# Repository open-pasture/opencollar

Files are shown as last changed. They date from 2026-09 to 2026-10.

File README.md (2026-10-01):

# OpenCollar

Open hardware virtual-fence collar. Off-the-shelf parts, open protocol, works with any software that speaks it.

- `docs/BUILD-LOG.md` — dated record of every step, result, and decision
- `docs/PROTOTYPE-V0.md` — current state of the V0 prototype
- `docs/V1-DESIGN.md` — the V1 collar design and cost estimates
- `docs/MANUFACTURING.md` — how we get to 1,000 collars, and why FCC and carrier approval matter
- `docs/BOARD-DESIGN.md` — designing the custom board on a small budget
- `docs/DESIGN-PHASE.md` — board design toolchain and workflow (KiCad + SKiDL)
- `docs/COLLAR-FIRST-PRINCIPLES.md` — the slim collar worked out from first principles
- `docs/TEST-FIXTURE.md` — how every board gets tested, explained from zero, with pictures
- `docs/CARRIER-EXPLAINED.md` — every part on the carrier board, what it does, and where it sits in the collar
- `docs/STRATEGY.md` — product strategy and licensing
- `hardware/prototype-cart.md` — parts for the first prototype
- `hardware/orders-2026-09-26.md` — what was ordered and paid
- `hardware/tools.md` — tools for building a collar
- `hardware/bom.md` — parts list
- `hardware/photos/` — build photos

## Licence

OpenCollar is open so anyone can build, repair and improve their own collar.

| What | Licence | Folders |
| --- | --- | --- |
| Firmware, scripts and the protocol | [Apache-2.0](LICENSE) | `firmware/`, `protocol/`, and code anywhere else |
| Hardware and CAD (boards, enclosure, print files) | [CERN-OHL-W-2.0](LICENSES/CERN-OHL-W-2.0.txt) | `hardware/`, `mechanical/` |
| Docs, photos and renders | [CC BY 4.0](LICENSES/CC-BY-4.0.txt) | `docs/`, `hardware/photos/`, `mechanical/renders/` |

In plain terms:

- **Firmware and protocol:** use them for anything, including closed products. Keep the copyright notice and [NOTICE](NOTICE).
- **Hardware:** build, sell and change the boards and the enclosure. If you ship a modified version of these design files, publish your changes to them under the same licence. Your own add-ons can stay closed.
- **Docs:** reuse them with credit to openpasture.

Third-party files keep their own licences: `firmware/boards/makerdiary/` (Apache-2.0, plus Nordic's 5-clause licence where its headers say so) and `firmware/third_party/monocypher/` (CC0 or BSD-2-Clause).

The names openpasture and OpenCollar and the openpasture logo aren't covered by these licences; see [NOTICE](NOTICE). Contributing: [CONTRIBUTING.md](CONTRIBUTING.md).

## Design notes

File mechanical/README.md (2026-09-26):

# Mechanical

Printed parts for the collar. Every part is a Python script run by Blender, so a dimension change is a one-line edit and a rebuild. See `../docs/DESIGN-TOOLING.md` for why.

## Layout

| Path | What |
| --- | --- |
| `parts/*.py` | One script per part. Builds the geometry, then calls `oc.finish()` |
| `lib/oc.py` | Shared helpers: primitives, booleans, export, renders, checks |
| `lib/collar.py` | V1-alpha geometry (top unit, clamp bars, bay), shared by part scripts and the assembly |
| `assembly/collar.py` | The whole collar on a strap with the bought parts inside; saves `collar_v1_alpha.blend` and presentation renders to `renders/collar/` |
| `PRINT-LIST.md` | What to print, how, and the hardware list, for the fabrication partner |
| `lib/dims.py` | Every bought-part and tolerance dimension, with its source. Parts import from here |
| `exports/<part>/*.stl` | Print files for the fabrication partner (mm) |
| `reference/vendor/` | Vendor drawings and CAD (nRF9151 STEP, Eagle boards, vent and panel drawings). Local only, not committed; sources in `lib/dims.py` |
| `renders/<part>/` | Review images (front, side, top, bottom, iso, section) and `report.json` |

## Build

```sh
./build.sh            # every part
./build.sh seal_box   # one part
./package.sh          # rebuild everything, render the assembly, zip a share package into ../../output/
```

Needs Blender 5.x at `/Applications/Blender.app` (override with `BLENDER=/path/to/blender`). Takes a few seconds per part.

## What every build checks

A part fails the build (non-zero exit) unless:

1. **Manifold** (watertight) with outward normals.
2. **Walls** no thinner than the part's minimum (ray cast inward from every face, like Blender's 3D Print Toolbox).
3. **Size** matches the spec in the script.
4. **Clearance**: no overlap with reference bodies (the bought parts it has to hold).

It also reports volume, solid mass in the chosen material and downward-facing overhang area, and renders six views, including a section cut with cut faces in red.

## Parts

| Part | Files | Print |
| --- | --- | --- |
| `fit_test` | `fit_test.stl` | Flat, engraved face up |
| `seal_box` | `seal_box_box.stl`, `seal_box_lid.stl` | Box open side up; lid groove side up |
| `top_unit` | `top_unit_base.stl`, `top_unit_lid.stl`, `top_unit_clamp_bar.stl` (×2) | Base underside down, lid rim down, both with tree supports; bars flat |
| `bay` | `bay_cradle.stl`, `bay_ballast_module.stl` | Cradle on its side; module top face down |

The collar parts are draft 1: print the fit test and seal box first, put the winning sizes into `lib/dims.py`, rebuild, then print the collar.

## First print run (for the fabrication partner)

Material for everything: **ASA**, light grey or white, 0.2 mm layers, 6 perimeters (walls ≥ 2.4 mm), 40 % infill.

1. **`fit_test`**: one plate that sets our tolerances for your printer. Engraved numbers are the designed size in mm.
   - Row A: M3 × 4 brass heat-set inserts (Adafruit 4255). Press one into each hole with the iron; which holds best without bulging the plastic?
   - Row B: M3 screw clearance. Which lets an M3 screw drop through without rattling?
   - Row C: 2 mm silicone O-ring cord. Which grips the cord and leaves it standing about 0.5 mm proud?
   - Row D: M6 × 0.75 tap drill. Tap each and screw in the vent; which threads cleanly and seals on its O-ring?
2. **`seal_box`**: the seal the top unit will use. Fit 4 inserts, press about 213 mm of O-ring cord into the lid groove (superglue the butt joint), tap the lid's centre hole M6 × 0.75 for the vent, close it with 4 × M3 × 8 socket-head screws and a dry paper towel inside. Hold it 1 m under water for 30 minutes, then check the towel.

Send back: the winning size for each row, whether the box stayed dry, printer and material used, and any print problems (warping, stringing in holes, layer splits).

## Still to measure

Not published anywhere; needed before the top unit and strap mount are drawn. Calipers on the real parts:

- Strap thickness (Heritage 1-3/4" double-thick nylon)
- MAX-M10S breakout height (SMA is tallest), bq24074 board height
- GPS patch total height (ceramic + LNA board + shield) and cable length
- LTE flex antenna size and cable length
- Li-ion pack lead length

## Live sessions

For looking around and quick edits, Blender runs with the MCP for Blender add-on (auto-starts its server on port 9876 when Blender opens) and Claude Code has the `blender` MCP server registered. Anything worth keeping goes back into a script here.

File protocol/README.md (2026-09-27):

# Collar protocol, v1

How software talks to an OpenCollar: boundaries and configuration go down,
acks and position reports come up. Any software that speaks this can run the
collars; openpasture is the first. Its side of the same formats is
[`crates/op-protocol`](https://github.com/open-pasture/openpasture/tree/main/crates/op-protocol)
and the
[Device endpoints](https://github.com/open-pasture/openpasture/blob/main/docs/API.md#device-endpoints-collars)
section of `docs/API.md` in open-pasture/openpasture. The server contract they
grew from is in [`contracts.md`](contracts.md).

Status: firmware 0.2 implements everything here and checks it against the
shared test vectors. Boundary download over LTE waits for the SIM; until then
a signed command can be pasted on the serial console (see Provisioning).

## Principles

- **Fence logic runs on the collar.** The collar holds its boundary and cues
  the animal without the network. The server only changes what the boundary is.
- **The collar keeps the last good boundary.** A lost connection, a bad
  message, a power cut or a reboot never leaves an animal without a fence.
- **Versions only go up.** A collar accepts only versions above every version
  it holds.
- **Everything is signed and acknowledged.** A boundary counts as active only
  once the collar reports it applied.
- **GNSS time is the collar's only clock** for when a boundary takes effect.
  Nothing unsigned from a server sets it.
- **Only a crossing is cued.** See below.

## Collar rule: only cue a crossing

The collar cues "outside" only when the animal goes from inside (or the
warning zone) to outside under the boundary it holds.

- At boot and whenever a new boundary is applied, the fence is **unarmed**. The
  first fix inside the fenced area arms it. If that fix is in the warning
  zone, the warning cue plays at once, which is how a moved boundary pushes an
  animal.
- While unarmed and outside, the collar is silent and reports state `outside`.
  A boundary that leaves an animal outside never cues it.
- A crossing cues the outside tone for up to 10 s, then disarms. An animal
  walking back in is not cued in the warning zone on its way; a fix clear of
  the warning zone arms the fence again.
- Warning-zone cues are otherwise unchanged: louder toward the edge, at most
  20 s of continuous cueing, then 30 s of rest.
- Holes work the same way: walking into a hole is a crossing (outside tone up
  to 10 s, then disarm). A hole drawn on top of an animal leaves it outside
  after rearm: silent while it walks out, armed once clear.

Why: an audio cue only teaches when the animal can escape it by moving away
from the edge. A fence drawn on top of an animal, or behind it, gives no
direction, only noise. In the firmware this is `cue.c`.

## Limits

| Limit | LEGACY (fw 0.1, no `caps`) | V0 (nRF9151, fw 0.2) | V1 (+16 MB NOR) |
|---|---|---|---|
| Outer ring vertices | 3–64 | 3–128 | 3–128 |
| Holes | 0 | ≤ 16 | ≤ 16 |
| Vertices per hole | – | 3–32 | 3–32 |
| Total vertices | 64 | ≤ 384 | ≤ 384 |
| Slots (1 active + staged) | 2 | 16 | 32 |
| Slot bytes (all held records) | – | ≤ 24 576 | ≤ 262 144 |
| Command size | – | ≤ 12 288 bytes | ≤ 12 288 bytes |
| Ids (`command_id`, `herd_id`, `collar_id`) | ≤ 64 bytes | ≤ 64 bytes | ≤ 64 bytes |

A slot record takes 192 bytes plus 8 per vertex (`int32` lon and lat × 1e7,
lossless because the server rounds to 7 decimals): 3 264 bytes at most, under
400 for a typical strip. Vertex counts are taken after conversion to e7 with
consecutive duplicates and a closing vertex removed.

## Boundary command (down)

```json
{
  "command_id": "bnd_01J8...",
  "herd_id": "herd_01J7...",
  "collar_id": "col_01J9...",
  "version": 57,
  "effective_at": "2026-09-27T12:00:00Z",
  "boundary": [[-92.41,38.12],[-92.4,38.12],[-92.4,38.13],[-92.41,38.13]],
  "holes": [[[-92.406,38.124],[-92.404,38.124],[-92.404,38.126]]],
  "cue_mode": "track",
  "warn_m": 5.0,
  "hysteresis_m": 1.0,
  "sig": "base64..."
}
```

- Rings are unclosed `[longitude, latitude]` arrays, WGS 84, at most 7
  decimals. Winding is ignored. `holes` is omitted when empty.
- `herd_id`: the herd the boundary is for. A collar rejects another herd's
  boundary (`wrong_herd`). Commands without it (older servers) are accepted.
- `collar_id`: only on one collar's own boundary (escape pens, per-collar
  restaged copies). Signed, so it can't be replayed to another collar.
- `cue_mode`: `audio` (the default, never sent) or `track`: evaluate the
  fence and report state, with no sound, no cues and no episodes.
- `effective_at`: absent means now. Whole seconds, `Z`.
- `warn_m`, `hysteresis_m`: absent means the collar's defaults (5 m, 1 m).
- Every new field is optional and omitted when empty or default, so a
  V0-shaped command serializes byte for byte as it did before v1.
- **Negotiation:** the server never sends a field that is not in the collar's
  `caps` (`holes`, `slots`, `collar_id`, `cue_mode`, `episodes`, `config`).
  LEGACY collars get the outer ring fitted to 64 vertices with holes dropped;
  the server's own fence for that collar uses the same ring.

### Signing

Ed25519 over `canonical_json(command without "sig")`: object keys sorted
bytewise, no whitespace outside strings, strings and numbers exactly as
serde_json writes them (shortest round trip, so `5.0` stays `5.0` and tiny
values print as `1e-7`). The server's wire body is serde_json compact output,
so every token on the wire is already canonical; the collar only reorders
keys and strips whitespace.

How the collar checks it, without building a JSON tree: objects occur only at
the top level, so it records up to 16 top-level key/value spans, sorts them
by key bytes and streams `{"key":value,...}` (value tokens copied verbatim,
whitespace outside strings removed, `sig` left out) straight into SHA-512
(Monocypher: `crypto_sha512_*`, `crypto_eddsa_reduce`,
`crypto_eddsa_check_equation`). Unknown top-level keys are signed and ignored.
Numbers may use exponents (`1e-7`); coordinates are converted to e7 integers
exactly from the decimal text, with no float round trip (half away from
zero).

Checked in this order; the first failure is the rejection code:

1. `too_large`: more than 12 288 bytes.
2. `bad_json`: not UTF-8; not one JSON object; a nested object anywhere
   (inside arrays too); arrays nested deeper than 4; a key with a backslash
   escape; a duplicate key; more than 16 keys; anything after the object; a
   raw control character in a string.
3. `bad_sig`: no `sig`; `sig` not a plain base64 string of 64 bytes (standard
   alphabet, canonical padding); a signature that doesn't verify with the
   server key from provisioning.
4. `bad_json`: the fields don't make a command: wrong types, a missing
   `command_id`, `version` or `boundary`, an id empty or over 64 bytes.

Then, in the slot store: `wrong_herd`, `wrong_collar`, re-ack or `stale`, the
shape rules, `slots_full`.

## Validation

A rejected command is acked `rejected` with a `code`. Every code except
`slots_full` is permanent: the server doesn't offer that version to that
collar again. `wrong_herd` is permanent only until the collar's config
changes: a boundary of the herd a collar was just moved to can reach it
before the config that moves it, so the server offers a version rejected
`wrong_herd` again once the collar reports a higher `device.config_version`.

- `bad_sig` · `wrong_herd` (herd_id present and not the collar's) ·
  `wrong_collar` (collar_id present and not the collar's) · `bad_json` ·
  `too_large` · `stale` (version below the highest held; a version equal to
  one held is re-acked with that version's current status instead)
- `out_of_range` (|lon| > 180, |lat| > 90) · `too_few_vertices` (a ring with
  fewer than 3 distinct vertices) · `too_many_vertices` (per ring or total) ·
  `too_many_holes`
- `self_intersecting` · `rings_cross` (touching counts) · `hole_outside`
  (every hole strictly inside the outer ring) · `holes_overlap`
- `zero_area` (outer ring under 1 m²) · `hole_too_small` (under 100 m²) ·
  `hole_too_close` (any two rings closer than **2 · warn_m + 2 m**, 12 m at
  the defaults, so no corridor is all warning zone)
- `bad_margins` (warn_m or hysteresis_m not finite or outside 0–1000) ·
  `slots_full` (no free slot, or the record doesn't fit the slot bytes left
  after pruning dead slots) · `bad_config` (config only)

The shape rules run in this order: `bad_margins`, `too_many_holes`,
`out_of_range`, `too_few_vertices`, `too_many_vertices`, `self_intersecting`,
`rings_cross`, `hole_outside`, `holes_overlap`, `zero_area`,
`hole_too_small`, `hole_too_close`.

How: topology (crossings, containment) with exact int64 orientation tests on
the e7 integers (each product is a longitude difference times a latitude
difference, under 2^63, and products are compared, not subtracted).
Containment of a hole is tested with its first vertex. Areas and gaps are
single precision in metres, projected about the outer ring's first vertex
(`kx = (float)(M_PER_DEG_LAT · cos(lat0) · 1e-7)`, `ky = (float)(M_PER_DEG_LAT
· 1e-7)`, `M_PER_DEG_LAT = 6 371 008.8 · π / 180`); an area is the fan sum from
the ring's first vertex, the gap between rings the least vertex-to-edge
distance. The firmware is built without fused multiply-add, so its
single-precision steps match openpasture's `op_geo::shape` operation for
operation (only `cos` comes from each side's own maths library, before the
result is rounded to single precision). The server checks gaps
against 2 · warn_m + 2.5 m, so rounding never makes a collar reject what the
server accepted.

## Geofence and cues

- Every ring is projected about the outer ring's first vertex (doubles).
  Inside = inside the outer ring and outside every hole, even-odd per ring.
  The margin is ± the distance to the nearest edge of any ring, positive
  inside; `nearest_ring` is 0 for the outer ring, 1.. for holes.
- The state machine, hysteresis and accuracy gating (fixes worse than 10 m
  don't change state) are those of firmware 0.1; the warning zone runs along
  hole edges too.
- Cue kinds: `warn` and `outside`. The boot chirp is not a cue.
- Episode: a run of armed warning cues, ending `turned_back` (reached
  inside), `crossed`, `rest` (the 20 s cap) or `boundary_changed`.

## Slots

The boundary in effect at time t is the **highest version whose activation
time (effective_at, else the time it was received) is at or before t**. A
staged version is **dead** when a higher version activates at or before it.

- **Accept** only versions above every version held.
- **Immediate** (no effective_at, or it has passed on the GNSS clock):
  validate, swap into the fence, rearm the cue, persist, drop every lower
  version, ack `applied`.
- **Future:** persist as staged, ack `received`, prune dead slots. No free
  slot or not enough slot bytes after pruning: `slots_full`.
- **Tick** on every fix, with that fix's GNSS UTC: apply the highest due
  version, drop lower ones, ack `applied` with the real apply time. Staged
  slots that are superseded get no ack; `slots` in the next report is the
  ground truth.
- **Reboot:** load the records, check format and CRC, enforce the latest
  active boundary at once (no clock needed); staged slots wait for the first
  GNSS fix.
- **First boot with no boundary:** no cues; fixes go up without
  `boundary_version`; poll every 60 s; the collar never invents a fence. An
  unprovisioned collar runs GNSS only.
- Any immediate boundary (sweep step, pen, farmer draw) drops lower staged
  slots, so the server re-stages schedules above it. A pen (`collar_id`
  command) drops that collar's staged slots; when the escape ends the server
  restages per-collar copies.
- **Herd change** (a signed config naming another herd): every staged slot
  whose `herd_id` is not the new herd is dropped, with no ack. The active
  boundary stays in force until a boundary of the new herd applies, so the
  collar is never left without a fence. `have` falls to the highest version
  still held and the next report's `slots` shows what is left, so the server
  serves the new herd's boundaries by `have` as usual. Slots whose command
  had no `herd_id` stay (they would be accepted in any herd). Boot drops them
  too, for a power cut after the config is stored.

### Persistence

Zephyr NVS on a 64 KB `storage` partition, by id: 1 provisioning, 2 pending
acks, 3 config, 0x100 + i slot i (one id more than the slot count, so a new
record is always written before the records it replaces are deleted). An
entry counts once it is completely written, so a power cut leaves the old
record or the new one, and boot tidies up whatever a cut left behind. The
store is behind `store.h`, so a NOR backend can replace NVS.

Slot record: a 192-byte header, then the vertices, outer ring first.

| Offset | Field |
|---|---|
| 0 | magic `OCS1` |
| 4 | format (1) |
| 5 | flags: applied, track, collar-scoped, has herd, has effective_at, has received_at, has applied_at |
| 6 | holes |
| 7 | outer ring vertices |
| 8 | total vertices (u16) |
| 10, 11 | command_id length, herd_id length |
| 12 | version (u32) |
| 16, 20, 24 | effective_at, received_at, applied_at (u32 Unix seconds) |
| 28, 36 | warn_m, hysteresis_m (f64) |
| 44 | hole lengths [16] |
| 60 | command_id [64] |
| 124 | herd_id [64] |
| 188 | CRC-32 of the whole record, this field zero |

## Endpoints

HTTP + JSON, `Authorization: Bearer <collar key>`.

- `GET /collar/v1/boundary?have=<highest version held, applied or staged>&free=<slots − held>&free_bytes=<slot bytes left>`
  → 200 with a command, or 204. The server picks:
  1. The collar's boundary set: its herd's boundaries, or its own
     `collar_id` boundaries while on an escape, split by the rule above into
     the active one A and the alive staged ones S (ascending).
  2. Leave out versions this collar rejected with a permanent code
     (`wrong_herd` only until its config version goes up; see Validation).
  3. If A.version > have, serve A.
  4. Else if `free` > 0 (absent = LEGACY, 1) and the lowest s in S with
     s.version > have fits `free_bytes` (absent = no byte limit), serve s.
  5. Else 204.
- `POST /collar/v1/ack` `{ command_id, version, status: received|applied|rejected, reason?, code?, at }`.
  `at` is the real apply time for `applied` (GNSS time, possibly in the past
  for a boundary applied offline); acks without GNSS time carry modem network
  time. Pending acks survive a reboot (NVS id 2) until delivered. When a
  command fails before its fields can be trusted (`bad_sig`, `bad_json`), the
  collar still acks it if its `command_id` and `version` can be read.
- `POST /collar/v1/report` → `{ latest_version, config? }`. `latest_version`
  is the highest alive version for this collar. `config` carries the collar's
  current signed config command when the report's `device.config_version` is
  lower or absent and the collar has the `config` cap. There is no unsigned
  server time or herd id: herd changes arrive only through the signed config,
  and nothing unsigned sets the collar's clock.

## Config command (down, inside the report response)

```json
{
  "command_id": "cfg_01J9...",
  "collar_id": "col_01J9...",
  "version": 3,
  "herd_id": "herd_01J7...",
  "endpoint": "https://farm.example.com/collar/v1",
  "report_s": 60,
  "poll_s": 60,
  "fast_report_s": 10,
  "fast_poll_s": 10,
  "fast_until": "2026-09-27T13:10:00Z",
  "sig": "base64..."
}
```

- A flat object, scanned, signed and canonicalized exactly like a boundary
  command. `command_id`, `collar_id`, `version`, `report_s` and `poll_s` are
  required.
- Checks, in order: ids (`bad_json`), `wrong_collar`, `stale` (version at or
  below the one held), `bad_config` (an interval outside 10–3600 s,
  `fast_until` without both fast intervals, an endpoint that isn't
  `https://…` or is over 256 bytes).
- `herd_id` replaces the provisioning herd for `wrong_herd` checks, and a
  new one drops the old herd's staged slots (see Slots: herd change).
- `report_s`/`poll_s` are the base cadence. `fast_*` apply until `fast_until`
  (GNSS time), then the collar returns to base without another command, so a
  collar that loses contact mid-sweep doesn't stay in fast mode. With no GNSS
  time since boot the base cadence applies.
- `endpoint`: absent keeps the current one. A new one is used from the next
  report; the first successful report there makes it the endpoint, and if it
  has failed for 24 h the collar goes back to the previous one, so a bad URL
  never strands it.
- The collar persists the config (NVS id 3), applies it at boot and reports
  `device.config_version`. A rejected config is reported once as
  `device.config_reject {version, code}`, and the server stops resending that
  version.

## Position report (up)

Sent on the report cadence. Fixes are batched. Every field added in v1 is
optional.

```json
{
  "boundary_version": 57,
  "device": {"fw": "0.2.0", "caps": ["holes","slots","collar_id","cue_mode","episodes","config"],
             "limits": {"outer":128,"holes":16,"hole_vertices":32,"total":384,"slots":16,"slot_bytes":24576},
             "config_version": 3},
  "slots": [{"version":57,"status":"applied"},{"version":58,"status":"received","effective_at":"2026-09-27T12:00:00Z"}],
  "fixes": [{"at":"…","point":[-92.405,38.124],"accuracy_m":1.8,"sats":9,"cn0":41.0,"hdop":0.9}],
  "cues": [{"at":"…","kind":"warn","level":2,"dur_ms":300,"margin_m":1.4,"ring":2,"boundary_version":57}],
  "episodes": [{"start":"…","end":"…","boundary_version":57,"ring":2,"cues":4,"max_level":3,"min_margin_m":0.8,"outcome":"turned_back"}],
  "battery": 0.81,
  "health": {"fix_attempts":120,"fix_ok":118,
             "cell": {"rsrp_dbm":-104,"rsrq_db":-11,"snr_db":6,"mode":"ltem","band":12,"cell_id":"1A2B3C","tac":1234,"at":"…"},
             "still_s":40,"tilt_deg":12,"temp_c":21.5,"battery_v":3.31,"charging":true,"uptime_s":86400,"reset":"power_on"}
}
```

- `boundary_version`: the fence the collar is enforcing. On cues and
  episodes always; on fixes only when it differs from the report's (a staged
  boundary applied offline can split one batch).
- `slots` present is the complete list the collar holds (the server replaces
  its record of them); absent means unknown (LEGACY).
- `cell` only when measured (never on GNSS-only boards). `still_s` and
  `tilt_deg` only with an IMU.
- Training mode has no collar flag: only `warn_m` changes.

## Provisioning over USB serial

The collar's card carries a QR code with one compact JSON payload:

```json
{"v":1,"c":"<collar id>","h":"<herd id>","k":"<collar key>","e":"<base>/collar/v1","s":"<server public key, base64>"}
```

The collar reads lines on its console UART (the board's USB serial, 115 200
baud). A handheld USB scanner in keyboard mode types the QR into a serial
terminal, so a printed card is enough to set up a collar. Physical access is
ownership: provisioning is allowed at any time.

| Line | Reply |
|---|---|
| `provision <payload>` | `ok <collar id>`, or `error <code>` |
| `status` | `collar <id> herd <id> fw 0.2.0 config <version or -> active <version or -> slots <versions or ->` (`unprovisioned fw 0.2.0` before provisioning) |
| `boundary <command>` | `applied <version>`, `received <version>`, `rejected <version> <code>`, or `error <code>`: the same path as a download |
| `config <command>` | `ok <version>`, or `error <code>`: the same path as a report response |

Provisioning checks the payload in this order, each failure being its code:
`bad_json` (not a flat JSON object), `bad_version` (`v` is not 1),
`bad_collar_id` / `bad_herd_id` (not a string of 1–64 bytes), `bad_key` (`k`
not 16–128 printable ASCII characters), `bad_endpoint` (`e` not `https://…`
or over 256 bytes), `bad_server_key` (`s` not base64 of 32 bytes). Unknown
keys are ignored. A valid payload wipes slots, config and pending acks first
(no boundary, so no cues), then is stored as sent in NVS id 1
(`error store_failed` if the flash write fails) and checked again at every
boot. Other replies: `error unprovisioned`, `error too_long`, `error
unknown_command`.

## Test vectors

openpasture writes them (`crates/op-protocol/tests/vectors/`, regenerated by
`OP_WRITE_VECTORS=1 cargo test -p op-protocol --test vectors`) and the
firmware copies them byte-identical into `firmware/tests/host/vectors/`. Both
sides run every case. Signing key: Ed25519 seed bytes `00 01 02 … 1f`.

| File | Cases |
|---|---|
| `commands.json` | wire text as received: V0 shape, holes, collar_id, compact and pretty, shuffled keys, `1e-7`, tampered and stripped fields, duplicate keys, nested objects, more than 16 keys, oversize; expected code and canonical bytes |
| `config.json` | valid, missing collar_id, wrong collar, stale, bad intervals, http endpoint, duplicate keys |
| `shapes.json` | each shape code minimal, exact limit passes and limit + 1 fails, both windings, gaps at ±0.1 m |
| `geofence.json` | margins (1 mm), inside, nearest ring, around and inside holes |
| `slots.json` | supersede, dead prune, duplicate re-ack, stale, slots_full by count and by bytes, boot without clock, wrong collar |

Cases the shared files don't have yet run from `firmware/tests/host/local/`
in the same format, until openpasture adds them: `slots.json` there has the
herd change (step `{"op": "set_herd", "herd_id": …}`, the signed config's
herd taking effect).

## Transport

HTTP + JSON over LTE-M for now, to the endpoint from provisioning or config.
The messages may map one to one onto CBOR later.

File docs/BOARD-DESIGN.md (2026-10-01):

# Designing the board without a big budget

Written 2026-09-26. The custom board is the step that makes 1,000 collars possible (`MANUFACTURING.md`). We don't have $25k for a design firm, so we build it ourselves with free tools, agents, and the free design reviews chip makers offer.

## Two boards, in order

### 1. Carrier board (start now)

A simple board that the parts we already bought **plug into**: the nRF9151 Connect Kit, the MAX-M10S breakout and the IMU sit on headers. The carrier board itself holds only the easy parts:

- Charger (bq24074 for now) and thermistor connector
- Buzzer driver and piezo
- Connectors for the panels, battery and strap harness
- Mounting holes that match the shell

**Why first:**
- **No radio design on it.** The antennas stay on the boards Nordic and SparkFun already got right, so there's nothing to certify and nothing hard to get wrong.
- **Cheap.** A 2-layer board; 5 assembled boards from JLCPCB cost roughly $30–100.
- **Useful straight away.** It replaces the jumper-wire mess in the alpha collars (5–10 units).
- **Teaches the whole process** (schematic, layout, ordering, assembly, bring-up) on a board where mistakes cost $50.

### 2. Integrated board (after the carrier board works)

Everything on one 4-layer board: the nRF9151 SiP, the GNSS module and antennas, a LiFePO4 charger (BQ25798), IMU, flash, eSIM and buzzer driver. The hard part is the radio sections (LTE and GNSS antenna feeds, matching, ground plane). We don't invent those:

- **Copy the reference designs exactly.** Nordic publishes nRF9151 reference layouts; u-blox publishes MAX-M10S integration guides. Following them closely is also what lets us reuse their certifications.
- **Free expert review.** Nordic reviews customers' schematics and layouts through private DevZone tickets. u-blox offers design support too. That's the review we'd otherwise pay a firm for.
- **Spins cost $100–300** at JLCPCB for 5 assembled boards. Plan on two or three spins.

## What agents can do

| Job | How |
| --- | --- |
| Part choice | Pick parts in JLCPCB's stocked library ("basic" parts avoid setup fees), check stock and price |
| Schematic | Write the circuit as code with **SKiDL** (Python that compiles to a KiCad netlist). Agents are good at text; every change is a reviewable diff |
| Checks | `kicad-cli` runs electrical and design-rule checks and exports renders, so agents can check their own work in a loop (like the Blender self-review in `DESIGN-TOOLING.md`) |
| Layout | Place parts by script; route the simple nets with an autorouter (Freerouting). Radio and power sections are placed by hand, following the reference layouts |
| Review prep | Assemble datasheet checklists, the power budget and a design-review pack for Nordic DevZone |
| Ordering | Generate Gerbers, the BOM and pick-and-place files in JLCPCB's format |

Community KiCad MCP servers exist and are worth trying so an agent can drive KiCad directly.

## Open-source reference designs: learn from them, don't copy them

The SparkFun and Adafruit breakout designs are published, but under **CC BY-SA** (share-alike). Copying them into our board would force our board under share-alike terms, which clashes with the licence plan in `STRATEGY.md`. Use them to learn and check our work, then draw our own circuits from the **chip makers' datasheets and reference designs**, which carry no such condition. The Makerdiary board files we vendored are Apache-2.0 and fine to reuse.

## What Cody can put in (time, not money)

- **KiCad is installed.** Do one beginner tutorial, so you can read a schematic and a layout when agents produce them. A weekend.
- **Bring-up.** When the carrier boards arrive: plug in parts, measure with the multimeter, report back. Agents can't hold a probe.
- **Shell measurements.** The board outline comes from the shell. Once the printed top unit exists, measure the inside space.
- **Accounts.** A Nordic DevZone account (free), a JLCPCB account.

## Costs

| Step | Cost |
| --- | --- |
| KiCad, SKiDL, Freerouting | Free |
| Carrier board, 5 assembled | ~$30–100 per spin |
| Integrated board, 5 assembled | ~$100–300 per spin, 2–3 spins |
| Nordic / u-blox design review | Free |
| **Total to a working integrated board** | **Under ~$1,000** plus our time |

Certification is still the expensive part later, but it only starts once this board works.

## Next steps

1. ~~Install KiCad and SKiDL.~~ Done 2026-09-26; see `DESIGN-PHASE.md`.
2. Write the carrier-board spec: which headers, which connectors, board size (from the shell design).
3. Agent drafts the carrier-board schematic in code, runs checks, renders it for review.
4. Layout, order 5 from JLCPCB, bring them up on the bench.

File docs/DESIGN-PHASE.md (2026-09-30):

# Board design phase: how we work

Set up 2026-09-26. The plan and costs are in `BOARD-DESIGN.md`; this is the day-to-day method.

## Toolchain (installed on Cody's Mac)

| Tool | Version | Role |
| --- | --- | --- |
| KiCad | 10.0.6 | Board editor, libraries, checks, Gerber export. `/Applications/KiCad` |
| `kicad-cli` | 10.0.6 | Headless design-rule checks (DRC), renders, Gerbers, BOM. Linked in `~/.local/bin` |
| `kicad-python` | KiCad's bundled Python 3.9 with `pcbnew` | Scripts that build and edit boards. Wrapper in `~/.local/bin` |
| SKiDL | 2.3.0 (MIT) | The schematic, written as Python, compiled to a KiCad netlist |
| kicad-python (package) | 0.8.0 | KiCad 10's live API, for driving an open KiCad window later |
| uv | | Python environments per board project |

**Why SKiDL, not atopile:** atopile's standalone command-line tool is in maintenance mode and being replaced by a hosted app that needs an account. SKiDL is plain Python, MIT-licensed, has no account, and fits the "agents write text, humans review diffs" approach.

**Not installed yet:**
- **Freerouting** (autorouter). Needs Java; install when we reach layout.
- A **KiCad MCP server**. Worth trying once there's a real board to drive.

## Repo layout

```
hardware/
  carrier/                 carrier board (first board)
    pyproject.toml         SKiDL + kicad-python, managed by uv
    env.sh                 points SKiDL at KiCad's libraries
    smoke.py               toolchain check (LED + resistor + header)
    netlist_to_pcb.py      netlist -> .kicad_pcb with footprints and nets
    build/                 generated files (gitignored)
  integrated/              the full board (later)
```

Generated files stay out of git. The source of truth is the Python schematic plus the hand-edited `.kicad_pcb` layout once layout starts.

## The loop

```
spec (markdown) -> schematic.py (SKiDL) -> netlist -> .kicad_pcb -> DRC + render -> review
```

1. **Spec first.** Every board starts as a short markdown spec: what plugs in, every connector and its pinout, power paths, board outline and mounting holes, and which reference design each section copies. Nothing gets drawn until the spec is agreed.
2. **Schematic as code.** Each circuit block is a Python function (power, charger, buzzer, connectors) with the datasheet section it follows cited in a comment. `uv run python schematic.py` writes the netlist.
3. **Automatic checks every time.** SKiDL's electrical rules check (unconnected pins, drivers fighting); then `netlist_to_pcb.py` and `kicad-cli pcb drc`.
4. **Render and look.** `kicad-cli pcb render` produces top and bottom images. The agent reviews its own renders before showing anyone, the same way as the Blender loop in `DESIGN-TOOLING.md`.
5. **Layout in KiCad.** Scripts do the first placement from the shell outline; power and (later) radio sections are placed by hand following the reference layouts; simple nets can go to Freerouting. From here the `.kicad_pcb` is committed and edited in place.
6. **Review gates** before ordering:
   - Self-review: every pin checked against its datasheet, a power budget, DRC clean.
   - Cody reviews renders and the spec.
   - Integrated board only: Nordic DevZone schematic and layout review.
7. **Order** 5 boards from JLCPCB (Gerbers, BOM and pick-and-place from `kicad-cli`), then bring them up with the current-limited bench supply.

Commands:

```sh
cd hardware/carrier && source env.sh
uv run python smoke.py                                  # netlist in build/
kicad-python netlist_to_pcb.py build/smoke.net build/smoke.kicad_pcb
kicad-cli pcb drc --output build/drc.rpt build/smoke.kicad_pcb
kicad-cli pcb render --side top --output build/top.png build/smoke.kicad_pcb
```

The carrier board itself (rev A2):

```sh
cd hardware/carrier && source env.sh
uv run python schematic.py                                   # ERC + build/carrier.net
kicad-python layout.py build/carrier.net build/carrier.kicad_pcb   # placement, pours, silkscreen
kicad-cli pcb drc --severity-all --format json --output build/drc.json build/carrier.kicad_pcb
kicad-cli pcb render --side top --output build/top.png build/carrier.kicad_pcb
kicad-cli pcb render --side bottom --output build/bottom.png build/carrier.kicad_pcb
```

Routing (rev A2, A3): Inky routed the board in HeyPCB. Its export is committed as `pcb/heypcb/`, and `finish_routing.py` redoes the charger block from it and writes the routed board:

```sh
uv run python schematic.py                                   # rev A3 netlist, read by finish_routing.py
kicad-python finish_routing.py pcb/heypcb/opencollar-carrier.kicad_pcb pcb/carrier.kicad_pcb
kicad-cli pcb drc --severity-all --refill-zones --format json --output build/drc.json pcb/carrier.kicad_pcb
kicad-python fit_test.py pcb/carrier.kicad_pcb build/carrier-fit-test.pdf   # 1:1 paper fit test
kicad-python jlc_files.py pcb/carrier.kicad_pcb build/fab                    # JLCPCB BOM, CPL, Gerbers
```

`finish_routing.py` brings Inky's board up to the current schematic (new parts, values, footprints, nets), places what's new, and routes everything that changed. It needs Freerouting and a Java runtime in `build/tools` (gitignored; both free, nothing to install system-wide):

```sh
mkdir -p build/tools && cd build/tools
curl -sL https://github.com/freerouting/freerouting/releases/download/v2.4.1/freerouting-2.4.1.jar -o freerouting.jar
curl -sL "https://api.adoptium.net/v3/binary/latest/25/ga/mac/aarch64/jre/hotspot/normal/eclipse" | tar xz
```

## Known gap: a readable schematic

SKiDL writes netlists, not KiCad schematic sheets. That's fine for the carrier board, where agents and diffs do the reviewing. Nordic's review (and most humans) want a schematic PDF. Before the integrated board, either:

- generate schematic sheets from the same Python (write `.kicad_sch` directly), or
- draw the integrated board's schematic natively in KiCad, with agents editing the `.kicad_sch` text.

Decide when the carrier board is done.

## Rules we hold to

- **Datasheets over breakout boards.** SparkFun and Adafruit designs are share-alike licensed; use them to check our work, not as a source (see `BOARD-DESIGN.md`).
- **JLCPCB-stocked parts** unless there's a reason not to, preferring "basic" parts (no setup fee).
- **Test pads** for every rail and programming line, so a fixture can test the board later (`MANUFACTURING.md`).
- **Every board revision gets a build-log entry:** what changed, why, and what bring-up found.

## First task: the carrier board spec

`hardware/carrier/SPEC.md`, covering:
- Female headers for the nRF9151 Connect Kit, the MAX-M10S breakout and the IMU (or Qwiic sockets)
- bq24074 charger circuit (from TI's datasheet), thermistor connector
- Buzzer driver and piezo footprint
- JST-PH connectors for the battery and panels; the strap harness connector
- Board outline and mounting holes, from the printed top unit's inside dimensions
- Test pads

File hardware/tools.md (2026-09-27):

# Tools for building a collar

Ordered on Amazon 2026-09-26 (receipt goes to the other email address). Prices on that day.

| Tool | Pick | ASIN | $ |
| --- | --- | --- | --- |
| Soldering station (60 W, 900M-style tips) | YIHUA 926 III, includes helping hands | B082F1WKP9 | 49.99 |
| Heat-set insert tips (M2–M8), fit 900M irons | — | B0CS662NVK | 12.99 |
| Solder, 63/37 rosin core 0.8 mm | Kester 44 | B00AVLM4SO | 15.93 |
| Multimeter, auto-ranging true RMS | AstroAI | B071JL6LLL | 34.99 |
| Wire stripper 20–30 AWG | Klein 11057 | B000XEUPMQ | 21.97 |
| Flush cutters (2-pack) | Hakko CHP-170 | B0765LT5JG | 19.21 |
| Mini heat gun, for adhesive heat shrink | SEEKONE 350 W | B08VFY8THD | 19.99 |
| Metric ball-end hex keys (2.5 mm for M3) | GEARWRENCH 83521 | B098TYMJ3X | 7.99 |
| Kapton tape 1/2" (thermistor to pack) | — | B0DZCR4TKM | 5.35 |
| Super glue gel (joins O-ring cord) | Loctite Ultra Gel | B00ELV2D0Y | 4.49 |
| **Total** | | | **192.90** |

Not bought: USB-C cable and phone charger (assumed on hand), isopropyl alcohol, outdoor VHB tape.

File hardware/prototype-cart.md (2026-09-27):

# Prototype collar cart (simplified 2026-09-26)

The first build proves four things: GPS accuracy, the fence and cue, telemetry, and the physical collar (shell, strap, balance). Everything else waits for the second build.

Already owned: nRF9151 Connect Kit, LTE antenna, small U.FL GPS patch, SparkFun Qwiic Buzzer, 1200 mAh LiPo, jumper wires.

## Order (6 checkouts)

### DigiKey
| Item | Part | Qty | $ |
| --- | --- | --- | --- |
| SparkFun MAX-M10S GNSS breakout (SMA, Qwiic) | 1568-18037-ND | 1 | 45.95 |
| M6 screw-in ePTFE vent | 1754-1548-ND (VENT-PS2NGY-O8001) | 1 | 3.31 |

### Adafruit
| Item | Product | Qty | $ |
| --- | --- | --- | --- |
| Universal USB/DC/Solar charger, bq24074 (4.2 V fixed in hardware, 6–10 V solar in) | [4755](https://www.adafruit.com/product/4755) | 1 | 14.95 |
| Li-ion pack 3.7 V 6600 mAh, protection circuit, JST-PH | [353](https://www.adafruit.com/product/353) | 1 | 24.50 |
| 10K NTC thermistor (charge temperature cutoff) | [372](https://www.adafruit.com/product/372) | 1 | 4.00 |
| ISM330DHCX 6-DoF IMU, STEMMA QT/Qwiic (industrial, −40 to 105 °C) | [4502](https://www.adafruit.com/product/4502) | 1 | 19.95 |
| GPS active antenna 28 dB, SMA, 5 m cable (reference antenna for tests) | [960](https://www.adafruit.com/product/960) | 1 | 21.50 |
| SMA to U.FL adapter (existing patch on the M10S) | [851](https://www.adafruit.com/product/851) | 1 | 3.95 |
| STEMMA QT/Qwiic cable 100 mm | [4210](https://www.adafruit.com/product/4210) | 2 | 0.95 |
| STEMMA QT/Qwiic to female sockets 150 mm | [4397](https://www.adafruit.com/product/4397) | 2 | 1.25 |
| M3 × 4 brass heat-set inserts (50) | [4255](https://www.adafruit.com/product/4255) | 1 | 5.95 |

Adafruit drops cart adds from a guest session; sign in first.

### Amazon
| Item | ASIN | $ |
| --- | --- | --- |
| M3 304 stainless screw assortment | B0GHMM79M9 | 8.99 |
| 2 mm silicone O-ring cord | B00QVB0ZG6 | 15.39 |
| 1.25 mm 2-pin connector pigtails (pack to the kit's battery socket) | B013JRWCBU | 6.99 |
| 22 AWG silicone wire kit | B07G2JWYDW | 15.99 |
| Adhesive-lined heat shrink kit | B0BVVMCY86 | 13.99 |

### Voltaic
| Item | Part | Qty | $ |
| --- | --- | --- | --- |
| 1.2 W 6 V ETFE panel, 66 × 113 mm | P124 | 2 | 14.00 |

### Heritage Animal Health
| Item | $ |
| --- | --- |
| 48" cow neck strap, 1-3/4" double-thick nylon, blue | 23.10 |

### Hologram
LTE-M SIM, promo code FREEPILOTSIM (confirm nano size).

**Total: $260.31** plus shipping and tax.

## Not bought online
- About 500 g of steel for the ballast (flat bar or large fender washers).
- Superglue to join the O-ring cord.
- Soldering iron, solder, multimeter, flush cutters if you don't have them.
- Print material, from our fabrication partner.

## How it wires up (no configuration)
Panels (parallel) → bq24074 solar input. Li-ion pack → bq24074 battery plug, and the same pack → the nRF9151 kit's battery socket via a 1.25 mm lead. Thermistor taped to the pack. Every charger defaults to 4.2 V, correct for Li-ion, so nothing needs setting.

## Deferred to the second build
| Item | Why later |
| --- | --- |
| TI BQ25798 board + LiFePO4 cells, holders, BMS | LiFePO4 arrives with the V1-beta custom board |
| Power Profiler Kit II | Measure once firmware is power-optimized |
| Camera module (GoPro, microSD, power bank, mount, cables) | Add-on, not core |
| Wired-strap harness (M8 cordset + 2 sockets) | Only needed for powered modules |
| Piezo + driver | No louder than the Qwiic buzzer |
| Hall sensor + magnets | Product nicety |
| SPI flash, fuel gauge kit | Not needed yet |

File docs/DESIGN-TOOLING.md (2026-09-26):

# Designing the collar with Claude and Blender

How an agent designs collar parts in Blender and checks its own work.

## Two ways to drive Blender

### 1. Blender MCP (live session)

[blender-mcp](https://github.com/ahujasid/blender-mcp) is a Blender add-on plus an MCP server. Blender stays open on screen; the agent runs Python inside it, inspects the scene, and takes viewport screenshots to look at what it built.

Setup:
1. Install Blender (4.x) from blender.org.
2. Download `addon.py` from the blender-mcp repo. In Blender: *Edit → Preferences → Add-ons → Install from disk*, enable "Blender MCP".
3. In Blender's sidebar (N) → BlenderMCP tab → *Connect to Claude*.
4. Register the server with Claude Code: `claude mcp add blender uvx blender-mcp` (`uv` is already installed on this Mac).

Good for: interactive sessions where you watch the model take shape and steer it.

Cautions: it runs arbitrary Python inside Blender, so only point it at our own files. One Blender instance per server.

### 2. Headless Blender scripts (no MCP)

Blender runs from the command line with a Python script: `blender --background --python make_top_unit.py`. The script builds the part, exports STL/3MF, and renders review images.

Good for: repeatable, version-controlled parts. Every part is a script in the repo, so a dimension change is a one-line edit and a re-run. Works from any agent, no GUI needed.

### Recommendation

Use **both**: headless scripts are the source of truth (committed in `mechanical/`), and the MCP session is for looking around and quick iteration. Final parts must come out of a script so they're reproducible and open.

## How the agent checks its own work

A part isn't done until it passes all of these:

1. **Look at it.** Render fixed views (front, side, top, isometric, section cut through the middle) to PNG and view them. Blender MCP's viewport screenshot does the same live.
2. **Measure it.** The script prints overall dimensions, wall thicknesses at key points, and hole positions, and compares them with the spec (board outlines, cell sizes, connector cut-outs).
3. **Check it's printable.** Blender's bundled *3D Print Toolbox*: manifold (watertight), no inverted normals, minimum wall thickness, overhangs. Optionally a second check in Python with `trimesh`.
4. **Check the fit.** Import the real parts as reference bodies (the nRF9151 Connect Kit outline, MAX-M10S breakout, 26650 cells, M8 connectors, O-ring groove dimensions) and check clearances with boolean intersection: anything overlapping is a failure.
5. **Check mass and balance.** Compute volume × material density per part, plus component masses, and confirm the bottom module lands in the 450–650 g window.
6. **Export.** STL for the fabrication partner, with the print orientation and material noted in the file name or a README.

## Caveat: Blender is a mesh tool

Blender is great for shape, ergonomics and renders, but it isn't a parametric CAD program. Tolerances, O-ring grooves and screw bosses are harder to keep exact, and it doesn't export STEP files (the format injection moulders want).

For V1-alpha prints, Blender scripts are fine. Before production tooling, consider moving the enclosure to a code-based CAD library (**build123d** or **CadQuery**, both Python), which produces exact STEP files and fits the same agent workflow. The Blender scripts can stay for renders.

## Setup (done 2026-09-26)

- Blender 5.2.2 LTS in `/Applications` (checksum verified).
- MCP for Blender add-on (formerly blender-mcp) installed with `uvx mcp-for-blender install-addon` and enabled. Its server auto-starts on port 9876 when Blender opens. Telemetry is off in the add-on and in the server (`DISABLE_TELEMETRY=true`); the Poly Haven / Hyper3D / Sketchfab asset integrations stay off.
- Registered with Claude Code at user scope: `claude mcp add blender --scope user -e DISABLE_TELEMETRY=true -- uvx mcp-for-blender`. New Claude sessions pick it up.
- 3D Print Toolbox installed from extensions.blender.org (in Blender 4.2+ it's an extension, not bundled).
- `mechanical/` pipeline: part scripts, shared helpers, headless build with checks 1–3 and 6 above automated, plus the fit (clearance) check against reference bodies. See `mechanical/README.md`.
- Reference dimensions gathered into `mechanical/lib/dims.py`, each marked published, estimated, to measure, or to tune.

## Still open

- [ ] Measure the unpublished dimensions (list in `mechanical/README.md`)
- [ ] Ask the fabrication partner which printers and materials he has
- [ ] First print run: `fit_test` and `seal_box`, then put the winning sizes into `lib/dims.py`
- [ ] Mass and balance check (step 5) once the top unit and bay exist

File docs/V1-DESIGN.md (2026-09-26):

# OpenCollar V1 design

The best-value virtual fence collar: nothing extra, every part engineered properly.

## Principles

1. **Delete parts.** No base station, no wires running through the strap, no charging by the farmer, no app needed to set up. Every part we remove is a part that can't fail in a pasture.
2. **Position is the product.** A fence is only as good as the fix. We spend our engineering there first.
3. **The fence works with no signal.** Boundary logic runs on the collar. The network is for reporting and updates, never for containment.
4. **Serviceable, not disposable.** Sealed with gaskets, not potting. The strap, bottom module, battery and electronics can each be replaced on their own.
5. **Open.** Off-the-shelf parts, published design files, open device API. Anyone can build software for it or repair it.

## What it has to beat

From FCC teardowns and a published field study (`research/virtual-fence-gnss.md`):
- Commercial collars use u-blox single-band L1 receivers (Halter P5: M10; Vence: M8) with 18–25 mm patch antennas.
- Nofence measured **5.4 m accuracy error in the open and 7.6 m under forest**.
- Weight: Monil 1.0 kg, Nofence 1.3 kg, Halter ~1.4 kg.

## Targets

| | Target | Market today |
| --- | --- | --- |
| Accuracy error, open pasture | **≤ 2.5 m** (CEP50) | ~5.5 m |
| Accuracy error, under canopy | **≤ 4 m** | ~7.6 m |
| Fix availability when requested | **≥ 99 %** | Not published |
| Fix after sleep (hot start) | **≤ 2 s** | Not published |
| Runs with no sun | **≥ 60 days** | Varies |
| Maintenance | **None for a season**; no charging | Solar models similar |
| Total weight | **≤ 1.2 kg** | 1.0–1.4 kg |
| Setup per collar | **< 2 minutes**: scan, strap on, done | |
| Design life | 5 years, battery 2,000+ cycles | |

## Layout

```
            ┌──────────── solar ────────────┐
            │  panel  │ GNSS │  panel       │   top unit, sits on the neck
            │ (left)  │patch │  (right)     │   (everything electronic is here)
            └─────────┴──────┴──────────────┘
           /                                  \
   strap  |           50 mm polyester          |  strap, no wires inside
           \                                  /
                  ┌──────────────────┐
                  │   bottom bay     │   swappable module: ballast, camera,
                  └──────────────────┘   later battery (see BOTTOM-BAY.md)
```

**One sealed top unit, one swappable bottom module, one wired strap.** The bottom needs mass to keep the GNSS antenna facing up, so instead of a dead counterweight the bottom is a **bay** that takes interchangeable modules within a fixed mass window: plain ballast by default, a camera on a few collars, an extra battery later. Every collar has conductors in one fixed-length section of the strap, so any module plugs into any collar. The collar never depends on that wire: the top unit runs on its own battery and fence logic, and a damaged strap is detected, isolated and reported. Details in `BOTTOM-BAY.md`.

The GNSS patch sits at the crown of the top unit with nothing over it. The solar panels sit on the two sloped faces either side, like Nofence, so the panels never shade the antenna.

## Components

| Function | Part | Why |
| --- | --- | --- |
| **GNSS** | u-blox **MAX-M10S** | Same u-blox M10 generation Halter ships, but as a pre-tested module with a built-in LNA and SAW filter. Tracks GPS + Galileo + BeiDou + GLONASS with SBAS. < 25 mW tracking, low-power (LEAP) mode. |
| GNSS upgrade path | u-blox **MAX-F10S** (L1 + L5) | Same MAX form factor. If the dual-band tests win, it drops onto the same pads (confirm pin compatibility before layout) with a dual-band antenna. |
| **GNSS antenna** | 25 × 25 mm ceramic patch on a ≥ 60 mm ground plane, at the crown | Matches Nofence's patch but with a cleaner sky view and more ground plane. Kept away from the LTE antenna and the battery. |
| **Processor + cellular** | Nordic **nRF9151** SiP | Runs the firmware, LTE-M with NB-IoT fallback, and satellite NB-IoT (NTN) as a future option. Monil uses its predecessor. We already have firmware running on it. Its built-in GNSS stays available as a backup receiver. |
| **SIM** | Soldered eSIM (MFF2), multi-carrier | No SIM tray to corrode or shake loose. Roams to whichever carrier is strongest at the farm. |
| **Cellular antenna** | Flexible LTE antenna along the far edge of the top unit | Away from the GNSS patch |
| **Motion** | 6-axis IMU (ST LSM6DSV16X or Bosch BMI270) | Wakes GNSS on movement, slows fixes when the animal is lying down, fills short GPS gaps, logs collar rotation |
| **Storage** | 16 MB SPI NOR flash | Weeks of offline telemetry, firmware update images, event logs |
| **Audio cue** | Sealed piezo transducer, ~95 dB, behind an acoustic vent membrane | Loud, waterproof, no moving parts |
| **Battery** | 2 × 26650 **LiFePO4** in parallel (~22 Wh, ~170 g) | LiFePO4 over Li-ion: much safer in summer sun on an animal, 2,000+ cycles, flat voltage. |
| **Solar** | 2 × ~0.8 W ETFE-laminated monocrystalline panels (≈ 1.5 W total) | ETFE survives UV and scratching; glass doesn't belong on a cow |
| **Charger** | TI **BQ25798**, with its charge-enable held off by a hardware pull-up until firmware has set the LiFePO4 limit (3.6 V), so a blank or crashed board can't overcharge | MPPT solar charging, supports LiFePO4, stops charging below 0 °C (LiFePO4 must not charge when frozen) |
| **Fuel gauge** | Coulomb counter (e.g. MAX17260) | Real state of charge. LiFePO4's flat voltage makes voltage-based estimates useless. |
| **Power on** | Hall-effect sensor | Ships asleep. A magnet wakes it: no switch, no hole in the case. |
| **Status** | One LED behind a light pipe | Confirms power-on, network and GNSS fix at setup |
| **Service** | Pogo-pin pads under a screw cap | Debug and recovery flashing. Normal updates go over the air. |
| **Strap connector** | Sealed 4-pin connector to the wired strap, with short-circuit protection, plus power-path circuitry for an external LiFePO4 pack | Any bay module plugs in; the Battery Extension is a field upgrade (see `BOTTOM-BAY.md`) |
| **Bluetooth LE** (V1-beta) | Small BLE chip, e.g. Nordic nRF54L15 | Controls a camera module (Open GoPro API), identifies the fitted bay module, shelter beacons, phone setup |

### Electric pulse

Every commercial collar escalates from audio to a mild electric pulse, and containment depends on it. V1 ships **audio-first** while we validate position and behaviour at the pilot farm with his existing fence as the backstop. The top unit reserves space, electrode openings on its underside (resting on top of the neck) and a connector for a stimulus board, so adding it is fitting a board, not a redesign. It lives in the top unit, not the bottom bay, so every collar can enforce whichever module is fitted. It goes in once we have the welfare logic and field data to do it responsibly.

### Battery safety layers

1. Charge limit enforced in hardware: shipped collars hold charging off until the limit is set; the DIY build uses a Li-ion charger whose 4.2 V limit is fixed in hardware (no configuration at all).
2. Cell protection circuit (overcharge, over-discharge, over-current).
3. Temperature cutoff: no charging below 0 °C or when hot.
4. Firmware monitoring and reporting.

## Energy budget

| Load | Average |
| --- | --- |
| GNSS (adaptive: 1 Hz near the fence, every few minutes deep inside, off when lying down) | 5–10 mW |
| Cellular (LTE-M in power-saving mode, report every 5–15 min) | 2–4 mW |
| Processor, IMU, flash, sleep | ~0.5 mW |
| **Total** | **~10–15 mW ≈ 0.25–0.35 Wh/day** |

- **With no sun at all:** 22 Wh ÷ 0.35 Wh/day ≈ **60+ days**.
- **Solar:** 1.5 W × ~2.5 winter sun-hours in Tennessee × 50 % losses (angle, dirt, the animal shading itself) ≈ 1.9 Wh/day. That's about 5× what the collar uses in the worst month.
- To verify with the Power Profiler Kit before committing the battery size.

## Weight

| | |
| --- | --- |
| Top unit (electronics, battery, panels, shell) | ~450–550 g |
| Bottom module (ballast or camera) | ~450–650 g |
| Strap and buckle | ~100 g |
| **Total** | **~1.05–1.25 kg** |

## Enclosure

- **Pilot build:** printed by the fabrication partner in a tough, UV-stable material (ASA, or MJF PA12 dyed and UV-coated). Silicone O-ring seal, stainless screws, and a Gore-style vent to stop pressure changes pumping water past the seals.
- **Production:** injection-moulded PC/ASA. The pilot shell is designed with draft angles and wall thicknesses that carry over to moulding.
- **Tests before cattle:**
  - Submersion (IP67: 1 m for 30 min).
  - Drop onto concrete from 1.5 m.
  - 60 °C in direct sun.
  - −20 °C cold soak.
  - Rubbing against a post.
  - Pressure washing.
- **Strap:** standard 50 mm cattle neck belting with a buckle, replaceable without tools.

## Cost (rough, 20-unit pilot)

| | |
| --- | --- |
| nRF9151 SiP | $25–30 |
| MAX-M10S | $15 |
| Antennas (GNSS + LTE) | $10 |
| IMU, flash, fuel gauge, charger, power, piezo, eSIM | $20 |
| Battery (2 × LiFePO4 26650) | $12 |
| Solar panels (2) | $15–20 |
| PCB + assembly | $30–40 |
| Printed shell, gaskets, vent, hardware | $40–70 |
| Strap, buckle, bay cradle, ballast module | $20–30 |
| **Total** | **~$190–260** per collar at 20 units |

Plus data: LTE-M at a few KB per report is about $1–2/month.

## Cost at volume, with the pulse module (estimate, ~5,000 units)

Parts and assembly per collar:

| | Approx. |
| --- | --- |
| nRF9151 SiP | $15–18 |
| MAX-M10S | $8–10 |
| Antennas (GNSS + LTE) | $4–6 |
| IMU, flash, fuel gauge, charger, regulators, piezo, eSIM, hall sensor, passives | $10–12 |
| PCB, assembly, factory test | $8–12 |
| Battery (2 × LiFePO4 26650) | $6–8 |
| Solar panels (2, ETFE) | $6–8 |
| Injection-moulded shell, gaskets, vent, hardware | $6–10 |
| Wired strap + two IP68 connector pairs | $8–12 |
| Ballast module | $3–5 |
| **Pulse module**: boost stage, HV transformer and capacitors, energy-limiting and safety circuit, stainless electrodes | $8–12 |
| **Bill of materials** | **~$85–115** |

All-in per collar adds:

| | Approx. |
| --- | --- |
| Packaging, freight, duties | $5–8 |
| Warranty and returns reserve (~5 %) | $5 |
| One-time costs spread over 5,000 units: injection tooling ($30–60k); radio and carrier certification, FCC/ISED/CE plus US carrier approval ($40–80k); stimulus safety and regulatory testing | $15–30 |
| **All-in per collar** | **~$110–160** |

At 1,000 units, the one-time costs weigh far more ($70–140 per collar), putting all-in at roughly $170–270. Recurring: ~$1–2/month data per collar.

These are estimates, not quotes. Real numbers come from a costed BOM and quotes from an assembler and a moulder once the V1-beta board exists. Using the pre-certified nRF9151 keeps the certification cost toward the low end. Stimulus collars face extra rules in some markets (parts of Europe restrict them), which needs checking before selling outside the US.

## How we get there

1. **V1-alpha: dev boards in a real shell** (now).
   - nRF9151 Connect Kit + SparkFun MAX-M10S + IMU + solar charger + battery, in a printed top unit with a bottom bay (ballast module, plus one GoPro camera module) on a real strap.
   - Validates the layout, GNSS performance against V0, the energy budget and the firmware.
   - One collar first. Walk tests, then worn by a person, then on a cow alongside the pilot farm's fence. Build more once it works.
2. **V1-beta: one custom board.**
   - The same parts on a single 4-layer board shaped to the shell, factory-assembled (e.g. JLCPCB).
   - 10–20 units.
   - Firmware is the same as alpha.
3. **Pilot at the pilot farm.**
   - Passive tracking first, then audio cues, with his current system as the backstop.
   - Measure fix availability, accuracy, battery and durability against the targets above.
4. **Freeze V1.**
   - Publish the BOM, board files, shell, firmware and API.
   - Then add the stimulus module.

## What makes it better than the others

- **Position:** four constellations, a clean antenna placement and more ground plane, IMU-aided filtering and strict accuracy gating before any cue. Target is half the real-world error of today's collars, with a dual-band upgrade ready if the tests justify it.
- **Reliability:** no base station, no SIM tray, no charging, and nothing the fence depends on outside the sealed top unit. LiFePO4 for safety and life. Fence logic keeps working without signal.
- **Openness:** the only collar with published hardware, firmware and an open device API. Farmers can repair it, and any software can drive it.

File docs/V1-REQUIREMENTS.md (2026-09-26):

# V1 requirements

Running notes on what matters for the next hardware version. Ranked.

## 1. GPS uptime and accuracy (top priority)

A virtual fence is only as good as its position. A missed or wrong fix means either no cue when the animal is at the line, or a false cue when it isn't. Both teach the animal the wrong thing.

### What we want

- **Availability.** A usable fix (≤ 5 m estimated accuracy) whenever the firmware asks for one, including under tree cover, on hillsides, next to other cattle, and with the animal lying down or grazing head-down.
- **Accuracy.** Open sky: ≤ 2.5 m typical (V0 already does 2.0–2.2 m). Under canopy: ≤ 5 m typical.
- **Fast reacquisition.** A fix within seconds after sleep, so duty cycling doesn't create blind spots.
- **Resilience.** The collar recovers on its own from any GPS outage: no reboot needed, no stuck states.

### Known constraints of V0

- The nRF9151's built-in GNSS tracks **GPS + QZSS only**, single-band L1. No Galileo, BeiDou, or GLONASS. That's the biggest limit on satellite count under obstruction.
- Ceramic patch antenna, orientation not controlled.
- Cold start took ~3 minutes in open sky. No assistance data yet.

### Industry baseline (see `research/virtual-fence-gnss.md`)

Antenna on top with a heavy counterweight under the chin; single-band L1 multi-constellation receivers; adaptive fix rate (~1 Hz within ~20 m of the fence); fence logic on the collar. Best public claim is eShepherd's ±1 m near the fence. Nobody claims L5 or RTK. **Beating the industry on GNSS means L5, a better antenna, and better firmware, not RTK.**

### Direction for V1 hardware

1. **Add a dedicated multi-constellation GNSS receiver; keep the nRF9151 for LTE-M and assistance data.** The nRF91's built-in GNSS is GPS + QZSS only (~8–10 usable satellites) and shares time with the LTE radio, so fixes stall while the modem is busy.
   - **Default candidate:** u-blox **MAX-M10S**. L1, four constellations, < 25 mW continuous, low-power (LEAP) mode, ~$10–15.
   - **Accuracy candidate:** u-blox **MAX-F10S**. L1 + L5, 1.0 m CEP with SBAS (1.5 m without), ~€18. More power; needs a dual-band antenna. L5 mainly fights multipath near trees and the animal's body.
   - **Watch for V2:** u-blox F11 (dual-band at 7 mW in LEAP mode, modules due Q4 2026).
   - **Cheaper L1 alternative:** Quectel LC76G (< 9 mA, four constellations).
   - **Skip RTK.** Nobody uses it; the power and bandwidth cost isn't worth it for ~1 m.
2. **Antenna.** At least a 25×25 mm patch on a 50–70 mm ground plane. Our current small patch is likely the biggest single loss. For L1/L5, use a stacked dual-feed patch or a small quadrifilar helix: circular polarization, and it holds up better when the collar tilts or rotates.
3. **Mechanical.** Antenna in the top housing; battery in the bottom counterweight so its mass does double duty as ballast. Keep the LTE antenna and battery away from the GNSS antenna, and test whether LTE transmissions degrade GNSS.
4. **IMU.** Stationary → slow or stop fixes; walking → speed up; short GNSS gaps → dead reckoning for 10–30 s. Log orientation with every fix to measure time spent rotated.
5. **Shelter beacons** (BLE) so GNSS can switch off under roofs, as Nofence does.

### Levers to test (firmware)

1. **A-GNSS / P-GNSS over LTE** (nRF Cloud or u-blox AssistNow). Hot starts in ~1–5 s instead of minutes; cached predicted orbits cover periods without coverage.
2. **Adaptive fix rate.** One fix per 5–15 min when > 100 m from the fence, rising to 1 Hz within 20–30 m.
3. **Accuracy gating before any cue.** Estimated accuracy under ~3–5 m, at least 6 satellites, and 2–3 consecutive fixes agreeing. V0 only ignores fixes worse than 10 m.
4. **Filtering.** Constant-velocity Kalman filter using the receiver's accuracy estimate, with IMU input; reject jumps implying > 3 m/s.
5. **Health metrics.** Log fix availability, satellites used, C/N0, and time-to-fix on every fix. We can't improve what we don't measure.

### How we'll measure

- Same route, same time, several collars side by side, one variable changed at a time: open sky, tree line, under canopy, hillside, and lying on the ground.
- Record fix availability %, accuracy distribution (CEP50 / CEP95 against a surveyed point), time-to-fix, and current per fix.

## 2. Battery life and power

Needs PPK2 measurements. Industry: 20–70 Wh battery plus solar (Nofence 72 Wh). Rough estimate: duty-cycled M10 (~5 mW average) plus LTE-M in power-saving mode ≈ 0.2 Wh/day, so a 20–40 Wh battery with 1–2 W solar is in line with competitors.

## 3. Ruggedness and animal safety

TBD. Enclosure, strap, weight, heat, water, impact, and no pinch or rub points.

## 4. Connectivity

TBD. Cellular LTE-M first. Compare with coverage at the pilot farm; keep LoRa and base-station options open.

## 5. Openness and repairability

- Off-the-shelf parts wherever possible. Every part in the BOM should be buyable by one person.
- The electronics tray comes out of the enclosure independently of the strap.
- Full build docs, open protocol, host-testable firmware logic.

## Open questions

- Which GNSS chips are inside Nofence, Halter, and Vence? Their FCC internal photos should show them (links in `research/virtual-fence-gnss.md`).
- Is a dedicated GNSS receiver worth its extra power over the nRF9151's built-in one?
- What fix rate does reliable containment actually need?

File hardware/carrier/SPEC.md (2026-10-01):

# Carrier board, rev A3: spec

**Rev A3, 2026-09-27**, adds three parts and fixes one footprint. Same 65 × 58.5 mm board:
- A **fuel gauge** (MAX17260, high-side sense) counts the charge in and out of the pack, so the alpha collars log real daily energy (section 5).
- **16 MB SPI flash** (W25Q128JV) keeps raw GNSS logs through weak LTE, on four of the five spare GPIOs (section 2).
- **Reverse-battery protection** (AO3401A P-FET) in the harness BAT+ line, so a reversed pack can't destroy the charger, the gauge or the Kit (section 5).
- The charger's ISET, ILIM and TMR resistors move to JLCPCB basic values (section 4).
- **All plug-in sockets now use KiCad's `Pin1Right` footprint.** JLCPCB's own footprints for the hanxia sockets put pin 1's leg on the other side from `Pin1Left`, which A2 used; on the even-length sockets that can't be fixed by turning the part round (section 11, question 9).

Rev A 2026-09-26; **rev A2 the same day**, after the first-principles collar decisions (`docs/COLLAR-FIRST-PRINCIPLES.md`). Rev A2 changes:
- The board is a plain rectangle, no longer shaped to a shell: **65 × 58.5 mm** since 2026-09-27 (was 95 × 75), with the plugged boards tiled edge to edge and every carrier part underneath them.
- The battery lives in the bottom module and reaches the board over the harness.
- The harness is now M8 8-pin.
- Two cue ports (left and right ear pods) replace the on-board buzzer socket.
- Everything that leaves the box sits behind one switched, protected external bus.

The carrier is a 2-layer board inside the V1-alpha test box (draft 1 of the shell). The boards we already own plug into it. On the board itself: the solar charger, the strap-harness port, the connectors and the test pads. It has no radio circuits: the antennas stay on the Connect Kit and the MAX-M10S.

Sources, all kept locally in `mechanical/reference/vendor/` or `/tmp/ds` during the work:

| Ref | Document |
| --- | --- |
| [MD] | Makerdiary nRF9151 Connect Kit rev A: hardware diagram (front, back) and dimension drawing |
| [BQ] | TI BQ2407x datasheet, SLUS810N (Oct 2021) |
| [TPS25] | TI TPS2553 datasheet (current-limited load switch) |
| [TCA] | TI TCA4307 datasheet, SCPS270B (Nov 2023) |
| [TPS] | TI TPS63901 datasheet (the Connect Kit's 3.3 V regulator) |
| [BQ18] | TI BQ25180 datasheet (the Connect Kit's own charger) |
| [UBX] | u-blox MAX-M10S data sheet, UBX-20035208 R08 |
| [P124] | Voltaic P124 datasheet, Aug 2026 |
| [SF] | SparkFun MAX-M10S and Qwiic Buzzer Eagle board files, Adafruit LSM6DSOX/ISM330 board file |
| [SHELL] | `mechanical/lib/collar.py` and `dims.py` (V1-alpha draft 1) |
| [MAX] | Analog Devices MAX17260 datasheet (fuel gauge, rev A3) |
| [W25Q] | Winbond W25Q128JV datasheet, rev F (SPI flash, rev A3) |
| [AO] | Alpha & Omega AO3401A datasheet (P-FET, rev A3) |
| [JLC-FP] | JLCPCB/EasyEDA library footprints for each LCSC part (easyeda.com API), checked 2026-09-27 |

**Licence rule:** [SF] boards are CC BY-SA. We read them only for the **mating interface**: where their header pins are and what each pin is called. No circuit on this board comes from them. Every circuit comes from the chip maker's datasheet. The board is CERN-OHL-W-2.0.

## 1. What plugs in, and the recommendations

```
 P124 panel A ──PH2──┐
 P124 panel B ──PH2──┴─ Schottky OR ─► bq24074 IN      OUT ─► Kit J2 (battery input)
                                        │ BAT ◄── harness BAT+ ×2 ◄── 6600 mAh Li-ion (bottom module)
                                        │ TS  ◄── harness NTC     ◄── 10K NTC on the pack
                                        └ CHG, PGOOD, CE, ISET ─► Kit GPIO/ADC

 Connect Kit (2×20 socket) ── VIO 3.3 V + I2C2 ──┬── MAX-M10S (8 + 4-pin sockets)
                                                 ├── ISM330DHCX (9-pin socket)
                                                 ├── spare Qwiic socket (inside the box)
                                                 └── TCA4307 ── EXT bus ──┬── CUE_L Qwiic ── left ear pod buzzer
          3V3 ── TPS2553 (current limit) ── EXT_3V3 ──────────────────────┼── CUE_R Qwiic ── right ear pod buzzer
                        EXT_EN switches both                              └── harness SDA/SCL ── pack fuel gauge (later)
```

| Topic | Recommendation | Why |
| --- | --- | --- |
| Board shape | **Rectangle, 65 × 58.5 mm** | The size is set by the three plugged boards tiled edge to edge (Kit, MAX-M10S, ISM330). Everything the carrier itself carries fits underneath them, because they sit ~11 mm up on their sockets. The battery has left the top box, so nothing has to wrap around it |
| Connect Kit | **Four 1 × 10 SMD female sockets**, two end to end per row (J1–J4), 2.54 mm pitch, 8.5 mm tall | The Kit already has male pins fitted (parts photo). SMD sockets leave no tails under the board, which keeps the bottom flat for test pads and the fixture (section 7). JLCPCB stocks no 1 × 20 SMD socket (3 pieces of one Samtec part), so each row is two 1 × 10s butted together |
| MAX-M10S | **Female sockets** (8-pin edge row and 4-pin I2C row), not Qwiic | Sockets give us EXTINT (wake from standby), RESET_N, TIMEPULSE and UART, which Qwiic doesn't carry, and hold the board rigidly with no cable |
| ISM330DHCX | **Female 9-pin socket** | Brings INT1/INT2 to the nRF for wake-on-motion. An IMU should be screwed down, not hanging on a cable |
| Cues | **Two Qwiic Buzzers, one in each ear pod** on the strap, on Qwiic cables to CUE_L and CUE_R | Left/right cues need one sound source on each side of the neck (`docs/COLLAR-FIRST-PRINCIPLES.md` section 1). Qwiic Buzzers because one is owned and its driver is written; the second buzzer's address moves from 0x34 to 0x5B in software (SparkFun's two-buzzer example) |
| Spare Qwiic | One JST-SH 4-pin socket on the main I2C bus | For bench add-ons, or for a breakout that won't fit its socket |
| Charger | bq24074, **USB500 mode** (EN2 = 0, EN1 = 1), 1 A programmed charge, 500 mA input limit | USB500 is the only mode with input-voltage regulation (VIN-DPM 4.5 V), which stops the charger from dragging a panel down and collapsing it. The ILIM-resistor mode has no VIN-DPM ([BQ] 8.5, VIN-DPM: "EN2 = LO") |
| Kit power | bq24074 **OUT → Kit J2** (battery input) | This is how TI wires the system load ([BQ] 9.3.4, 10.1). Charge termination and the safety timers only see battery current. OUT has short-circuit protection, and the Kit boots from sun even with a flat pack. OUT is 4.3–4.5 V when there's input ([BQ] 8.5 VO(REG)), inside J2's 3.6–4.65 V range [MD] |
| 3.3 V | The Kit's VIO pin (TPS63901 buck-boost, over 400 mA at 3.3 V [TPS] p.1) powers every breakout | No regulator on the carrier. The breakouts and the nRF's GPIO bank share one rail, so nothing can back-power anything |
| Harness | **M8 8-pin**: BAT+ ×2, GND ×2, SDA, SCL, NTC, INT. The pack itself, not a 5 V bus | The battery is the counterweight (layout B). The charger's thermistor has to sit on the pack, which the 4-pin harness had no wire for. The power conductors are doubled so one broken wire doesn't drop the pack |
| External bus | Everything that leaves the box (both cue ports, the harness I2C) sits behind a **TCA4307 buffer plus a TPS2553 current-limited switch**, both switched by one GPIO, off by default | A chewed Qwiic cable or crushed harness can't hang the GNSS/IMU bus or short the Kit's 3.3 V. The buzzers are unpowered between cues, which removes their idle current |

## 2. Connect Kit sockets

Geometry [MD dimension drawing]: two rows of 20 pins at 2.54 mm pitch, **17.78 mm between rows** (the Ø1.4 corner holes are 1.27 mm in from each edge and in line with the rows). Pin 1 (VBUS) and pin 40 (VIO) are 3.81 mm from the USB end, and pins 20/21 are 3.81 mm from the antenna end (1.27 mm hole inset + 22.86 mm from the top hole to pin 32, and the 48.26 mm span from pin 1 to pin 20). Viewed from the top with USB up: pins 1–20 run down the left row, pins 21–40 run up the right row.

Pinout [MD front diagram] and what the carrier connects:

| Pin | Kit signal | nRF9151 | Carrier net | Notes |
| --- | --- | --- | --- | --- |
| 1 | VBUS | | TP only | USB 5 V from the Kit's USB-C. Not used for charging (see question 9) |
| 2 | VSYS | | TP only | Kit's system rail, an output (3.8–5.0 V) |
| 3 | GND | | GND | |
| 4 | ENABLE | | TP only | Kit power enable, left at its default |
| 5 | P9 | P0.09 | CHG_CE | bq24074 CE, 100 kΩ pull-down: charging on unless firmware drives it high |
| 6 | P8 | P0.08 | EXT_INT | Harness pin 6 (module interrupt, e.g. a fuel-gauge alert), 1 kΩ series + ESD, 100 kΩ pull-up to 3V3 |
| 7 | P7 | P0.07 | EXT_EN | TCA4307 EN and TPS2553 EN together. 100 kΩ pull-down: external bus off and unpowered |
| 8 | P6 | P0.06 | EXT_READY | TCA4307 READY, 10 kΩ pull-up to 3V3 [TCA] pin 5 |
| 9 | P5 | P0.05 | EXT_FAULT | TPS2553 FAULT (open-drain, over-current), 100 kΩ pull-up to 3V3 [TPS25] |
| 10 | P4 | P0.04 | FLASH_CS | W25Q128 /CS, 100 kΩ pull-up so it stays deselected while the nRF boots (rev A3) |
| 11 | P3 | P0.03 | FLASH_SCK | SPI clock (any nRF SPIM can use these pins) |
| 12 | P2 | P0.02 | FLASH_MOSI | Flash DI |
| 13 | P1 | P0.01 | FLASH_MISO | Flash DO |
| 14 | P0 | P0.00 | FG_ALRT | MAX17260 ALRT, open-drain, 100 kΩ pull-up to 3V3 (rev A3). The last spare GPIO |
| 15 | P31 | P0.31 | I2C_SCL | Main bus, as in today's firmware (I2C2) |
| 16 | P30 | P0.30 | I2C_SDA | Main bus |
| 17 | P29 | P0.29 | IMU_INT1 | |
| 18 | P28 | P0.28 | IMU_INT2 | |
| 19 | P27 | P0.27 | GNSS_EXTINT | Wake from software standby [UBX] Table 10 pin 5 |
| 20 | P26 | P0.26 | GNSS_RESET_N | Drive open-drain; low ≥ 1 ms resets [UBX] Table 10 pin 9 |
| 21 | A0 | P0.13 / AIN0 | VBAT_SENSE | 1 MΩ / 1 MΩ divider from BAT, 100 nF at the pin. Sources this high need the SAADC's 40 µs acquisition time |
| 22 | A1 | P0.14 / AIN1 | ISET_SENSE | 100 kΩ series from ISET. V = ICHG / 400 × RISET [BQ] eq. 3: charge current for telemetry |
| 23 | A2 | P0.15 / AIN2 | VIN_SENSE | 1 MΩ / 200 kΩ divider from charger IN (8 V → 1.33 V) |
| 24–26 | A3, A4, A5 | P0.16–P0.18 | NC | Spare analog |
| 27–28 | A6, A7 | P0.19, P0.20 | NC | |
| 29 | P21 | P0.21 | CHG_STAT | bq24074 CHG, 100 kΩ pull-up to 3V3 [BQ] 10.2.2.4 |
| 30 | P22 | P0.22 | GNSS_RXD | nRF TX → M10S RX (UARTE1) |
| 31 | P23 | P0.23 | GNSS_TXD | M10S TX → nRF RX |
| 32 | P24 | P0.24 | GNSS_PPS | TIMEPULSE. Input only: the M10S pin is shared with SAFEBOOT_N, so nothing may pull it low at boot [UBX] Table 10 note 15 |
| 33 | P10 | P0.10 | CHG_PGOOD | bq24074 PGOOD, 100 kΩ pull-up to 3V3 |
| 34 | P11 | P0.11 | TP only | UART0 TX to the Kit's interface MCU (console) |
| 35 | P12 | P0.12 | TP only | UART0 RX |
| 36 | SWDIO | | TP only | |
| 37 | SWCLK | | TP only | |
| 38 | RESET | | TP only | |
| 39 | GND | | GND | |
| 40 | VDD_GPIO (VIO) | | 3V3 | Must be set to 3.3 V (the factory setting, `viosel` on the Kit's interface MCU) |

Firmware impact: I2C2 stays on P0.30/P0.31, so the buzzer driver is unchanged, but the buzzers now sit behind the buffer. Firmware raises EXT_EN, waits for EXT_READY, then cues. New: UARTE1 for the GNSS, three ADC channels, the GPIOs above. UARTE0 (console) and TWIM2 (I2C) are already taken; UARTE1 is free.

**Kit battery feed.** The header has no battery pin; the battery reaches the Kit only through J2 (MX1.25-2P, underside) or test pad TP3 [MD back]. The carrier brings CHG_OUT and GND to two plated holes (2.54 mm pitch, strain-relief slot beside them). One of the 1.25 mm pigtails on order plugs into J2 and its wires are soldered into these holes.

## 3. Breakout sockets

Pin names and positions come from the [SF] board files (mating interface only).

**MAX-M10S (SparkFun GPS-18037), 38.10 × 30.48 mm.** Two female rows plus the four Ø3.3 corner holes for standoffs.

| Row | Pin | Name | Carrier net |
| --- | --- | --- | --- |
| J5 (8-pin, x = 1.27 mm, y = 24.13 → 6.35) | 1 | GND | GND |
| | 2 | 3.3V | 3V3 |
| | 3 | !SAFE | TP only (recovery) |
| | 4 | TXO | GNSS_TXD |
| | 5 | RXI | GNSS_RXD |
| | 6 | PPS | GNSS_PPS |
| | 7 | INT | GNSS_EXTINT |
| | 8 | !RESET | GNSS_RESET_N |
| J3 (4-pin, y = 29.21, x = 22.86 → 15.24) | 1 | GND | GND |
| | 2 | 3.3V | 3V3 |
| | 3 | SDA | I2C_SDA |
| | 4 | SCL | I2C_SCL |

**ISM330DHCX (Adafruit 4502), 25.40 × 17.78 mm.** 9-pin row at y = 2.54 mm, x = 2.54 → 22.86; Ø2.5 holes at (2.54, 15.24) and (22.86, 15.24) take standoffs on the opposite edge. The order below is from the LSM6DSOX board, which shares this outline. Check it against the ISM330 silkscreen when it arrives (question 4).

| Pin | 1 | 2 | 3 | 4 | 5 | 6 | 7 | 8 | 9 |
| --- | --- | --- | --- | --- | --- | --- | --- | --- | --- |
| Name | VIN | 3Vo | GND | SCL | SDA | DO | CS | INT1 | INT2 |
| Net | 3V3 | NC | GND | I2C_SCL | I2C_SDA | NC (address 0x6A) | NC (board pull-up keeps I2C mode) | IMU_INT1 | IMU_INT2 |

The aux row (SCX, SDX, OCS, SDO_AUX, GND) is left unsocketed.

**Cue ports CUE_L, CUE_R:** JST-SH 4-pin, Qwiic order (GND, EXT_3V3, EXT_SDA, EXT_SCL). A Qwiic cable runs from each to a Qwiic Buzzer in its ear pod. Buzzer addresses 0x34 (left) and 0x5B (right).

**Spare Qwiic:** JST-SH 4-pin on the main bus, inside the box: GND, 3V3, SDA, SCL.

**I2C pull-ups:**
- **Main bus:** 4.7 kΩ to 3V3. The M10S fits its own pull-ups by default; cut that jumper (question 5). The IMU's 10 kΩ can stay, giving ~3.2 kΩ.
- **EXT bus:** 4.7 kΩ to EXT_3V3, so nothing on it is back-powered while it's off. Cut the buzzers' pull-up jumpers too.

Addresses: main bus M10S 0x42, ISM330 0x6A. EXT bus buzzers 0x34 and 0x5B, and the pack's fuel gauge later (MAX17260 is 0x36). No clashes.

**EXT_3V3:** TPS2553 from 3V3, current limit set to ~250 mA by its ILIM resistor (value from [TPS25] in the schematic), EN tied to EXT_EN, FAULT to EXT_FAULT. A short in a cue cable trips the limit instead of pulling down the Kit's VIO.

## 4. Charger: bq24074 (from [BQ])

| Pin | Connection | Value | Reason and datasheet section |
| --- | --- | --- | --- |
| IN (13) | Charger input node; 10 µF 25 V to GND at the pin | | 1–10 µF bypass [BQ] Table 7-1. Rated for the ~8 V panel open-circuit voltage when cold, not 5 V |
| OUT (10, 11) | CHG_OUT → Kit J2 feed; 10 µF to GND at the pins | | 4.7–47 µF [BQ] Table 7-1; system load on OUT [BQ] 10.1 |
| BAT (2, 3) | Pack + over the harness (two conductors), through the reverse-protection FET and the gauge's 10 mΩ (section 5); 10 µF to GND | | 4.7–47 µF [BQ] Table 7-1. BAT is also the charger's voltage-sense input, so ~0.6 m of cable adds ~50 mV at 0.5 A: charging slows slightly near full, and the pack still finishes at 4.2 V as the current tapers |
| EN2 (5) | GND | | USB500 mode [BQ] Table 7-2 |
| EN1 (6) | 10 kΩ to OUT | | Logic high ≥ 1.4 V [BQ] 8.5; pin rated to 7 V [BQ] 8.1. Tied to OUT, not the Kit's 3.3 V, so the charger runs without the Kit |
| ILIM (12) | 4.7 kΩ 1 % to GND (A2: 3.24 kΩ) | ≈ 330 mA, only if ever switched to resistor mode (EN2 = 1, EN1 = 0), which we don't use | Must be fitted: "Leaving ILIM unconnected disables all charging" [BQ] Table 7-1; range 1.1–8 kΩ [BQ] 8.3 |
| ISET (16) | 1 kΩ 1 % to GND (A2: 887 Ω) | ICHG = 890 / 1000 = 0.89 A | [BQ] eq. 2. Input-limited to 500 mA, so the real charge current is ≤ ~480 mA, and the timers slow down to match [BQ] 9.3.5. Pre-charge 88 / 1000 = 88 mA [BQ] 8.5 |
| ITERM (15) | Open | Terminates at 10 % × ICHG = 100 mA | Default [BQ] 9.3.5.2 |
| TMR (14) | 68 kΩ to GND (A2: 71.5 kΩ) | Fast-charge timer 10 × 48 × 68 = 9.1 h at full rate; pre-charge 54 min | [BQ] eq. 6–7. Maximum allowed value: a 6600 mAh pack takes ~14 h at 480 mA, and the timer counts at ~half speed when input-limited ([BQ] 9.3.5.6), so ~20 h in practice. A timer fault clears when the input drops at night or firmware toggles CE [BQ] 9.3.5.6 |
| TS (1) | 10K NTC at the pack, over the harness NTC pin; 10 nF to GND against pickup on the cable; 10 kΩ DNP footprint for bench use without an NTC | Charges between ~3 °C and ~47 °C with a B3950 NTC | ITS = 75 µA; cold trip 2.1 V (28 kΩ), hot trip 0.3 V (4 kΩ) [BQ] 8.5, 9.3.6. The Adafruit 372 is B3950 (to confirm on the bag). With no NTC fitted, TS floats above the cold trip and charging stops: fail-safe |
| CE (4) | CHG_CE, 100 kΩ to GND | Charging enabled by default | [BQ] Table 7-1 (internal 285 kΩ pull-down, "do not leave unconnected") |
| CHG (9), PGOOD (7) | 100 kΩ to 3V3, to GPIO | | [BQ] 10.2.2.4. No LEDs: an LED to OUT would pull these nRF inputs above 3.3 V, and nobody sees LEDs inside a sealed shell |
| VSS (8) + thermal pad | GND, 3 × 3 array of vias in the pad | | [BQ] 12.1 |

**Inputs.** Each panel reaches IN through its own diode, so they can be paralleled on the board and neither can feed the other:

| Source | Path | Reason |
| --- | --- | --- |
| Panel A, panel B | J6 pins 1 and 3 → B5819W Schottky each (D1, D2) → IN | P124: Vmp 6.0 V, Voc 7.07–7.28 V, Isc 0.21–0.23 A [P124]. Diode drop ~0.3 V at 0.2 A is fine against a 6 V panel. A diode per panel stops a sunlit panel pushing current back into a shaded one |

**Thermal.** Worst realistic case is both panels at ~6 V and 400 mA into a pack at 3.4 V. That's P = (6 − 4.4) × 0.4 + (4.4 − 3.4) × 0.4 ≈ 1.0 W ([BQ] eq. 11), +45 °C at 44.5 °C/W ([BQ] 8.4). In a 60 °C shell that's ~105 °C, under the 125 °C thermal regulation. Pour copper on both layers under and around the IC.

**Not MPPT.** The bq24074 holds the panels at ~4.5 V at best, where the P124 is on the flat part of its curve: it gives almost its full current, at about 75 % of the power at Vmp. Current in ≈ current into the pack, so the harvest is counted in mAh (section 9). The BQ25798 board gets real MPPT.

## 5. Harness port (strap bus)

An 8-pin PH socket for the pigtail from the box's panel-mount M8 8-pin socket. The pack in the bottom module is on the other end. Pin order and wire colours follow the M8 8-pin cordset standard (IEC 61076-2-104, DIN 47100 colours). This is the V1 bus standard as well (`docs/COLLAR-FIRST-PRINCIPLES.md` section 4):

| M8 pin | Wire | Signal |
| --- | --- | --- |
| 1 | white | SDA |
| 2 | brown | BAT+ |
| 3 | green | GND |
| 4 | yellow | SCL |
| 5 | grey | NTC (pack thermistor to GND) |
| 6 | pink | INT (module interrupt, open-drain) |
| 7 | blue | GND |
| 8 | red | BAT+ |

- **BAT+ and GND** each come in on two conductors. GND goes straight to ground. BAT+ goes through the reverse-protection FET and the gauge's sense resistor to the charger's BAT node (below). The pack's own protection circuit is the only thing that can stop a short in the cable itself (upstream of this board), so the bottom module also gets a fuse at the cells (section 12).
- **I2C:** on the EXT bus behind the TCA4307 (section 3). The buffer's pins take 7 V absolute maximum [TCA] 5.1, and it clocks a stuck module free after ~40 ms [TCA] p.1.
- **ESD:** TVS protection on every line that leaves the box: harness BAT+, SDA, SCL, NTC, INT, and both cue ports' EXT_3V3, SDA, SCL (parts chosen in the schematic).
- Logic is 3.3 V with pull-ups in the top unit; modules must not pull up to anything higher.
- **Battery path (rev A3):** harness BAT+ (BAT_PACK) → AO3401A P-FET Q1 → BAT_CELL → 10 mΩ R24 → BAT.
  - **Q1** [AO]: drain to the pack, source to the board, gate to GND. A correct pack turns it on through its body diode (VGS = −VBAT, 47–60 mΩ at 4.5 V) and it then conducts both ways, so charging works. A reversed pack leaves VGS = 0, and the body diode blocks. VGS max ±12 V, VDS −30 V. It drops ~30 mV at 0.5 A.
  - **Fuel gauge U6, MAX17260** in high-side mode [MAX] Pin Descriptions, Figure 6. CSN and BATT go to the cell side of R24 and CSPH to the system side, both Kelvin-routed. CSPL goes to GND, TH (unused) to BATT, and the exposed pad to GND. BATT has 0.1 µF and REG 0.47 µF. 10 mΩ gives ±5.12 A range, 156 µA and 0.5 mAh resolution [MAX] Table 9. It's on the main I2C bus at 0x36, and ALRT goes to P0.00. The FET comes first, so a reversed pack never reaches the gauge's pins (absolute maximum −0.3 V).
  - FET plus sense add ~70 mΩ between the pack and the charger's BAT sense. That's ~35 mV at 0.5 A, on top of the cable's ~50 mV. It slows the end of charge slightly, and the pack still finishes at 4.2 V as the current tapers.
- **Flash (rev A3):** U7, W25Q128JV 16 MB, SOIC-8 208 mil, on SPI (section 2). Standard single-bit SPI, so /WP and /HOLD tie to VCC [W25Q] 4.3–4.4, with 0.1 µF at VCC. It idles at 10 µA typ (60 max) and drops to 1 µA after the Power-down command (B9h) [W25Q] 8.2.36, AC characteristics. Firmware powers it down between writes.
- **One battery path.** On the bench, a PH8 pigtail brings the Adafruit pack and its NTC to the harness socket. There's no second battery connector, so two packs can never be connected at once. (The bench-only J_BAT and J_NTC sockets were removed on 2026-09-27 to save space.)

## 6. Wire connectors

Board references in brackets (schematic.py).

| Ref | Connector | Mates with | Pins |
| --- | --- | --- | --- |
| J_SOL (J6) | JST-SH 3-pin, right-angle (1 A per contact; both panels peak at ≤ 0.46 A) | One pre-crimped SH3 pigtail; each panel's + to its own pin, both − to pin 2 | 1 = panel A +, 2 = GND, 3 = panel B + |
| J_HBUS (J13) | JST-PH 8-pin, right-angle | Pigtail from the M8 8-pin panel socket; on the bench, a PH8 pigtail to the pack and NTC | Section 5 |
| J_CUE_L, J_CUE_R (J11, J12) | JST-SH 4-pin | Qwiic cables to the ear-pod buzzers | GND, EXT_3V3, EXT_SDA, EXT_SCL |
| J_KIT (J5) | 2 plated holes | 1.25 mm pigtail (on order) into Kit J2 | CHG_OUT (+), GND (−), marked at the pads |
| J_QWIIC (J7) | JST-SH 4-pin | Qwiic cable, inside the box | GND, 3V3, SDA, SCL |

Plugged boards: Kit J1–J4, MAX-M10S J8 (8-pin) and J9 (4-pin), ISM330 J10.

There's no crimp tool in `hardware/tools.md`, so every mating half is a pre-crimped pigtail spliced with solder and heat shrink (both on hand).

## 7. Test pads

1.0 mm round pads on the **bottom** side, labelled in silkscreen, all on a 2.54 mm grid where the layout allows, so a pogo fixture can reach them. The bottom is otherwise empty.

Silkscreen labels are ≤ 5 characters: COUT/CIN = charger OUT/IN, SOLA/SOLB = panels before the diodes, X… = EXT bus (X3V3, XSDA, XSCL, XEN, XINT), KEN = Kit ENABLE, CHG/PG/CE = charger status and enable, SAFE/GRST/PPS = GNSS safeboot, reset, timepulse.

| Group | Pads |
| --- | --- |
| Rails | BAT, CHG_OUT, CHG_IN, SOLAR_A (before the diode), SOLAR_B, 3V3, EXT_3V3, Kit VBUS, Kit VSYS, and GND × 4 spread across the board |
| Programming | SWDIO, SWCLK, RESET, UART0 TX (P0.11), UART0 RX (P0.12), Kit ENABLE |
| Buses | I2C_SDA, I2C_SCL, EXT_SDA, EXT_SCL, EXT_EN, EXT_INT |
| Charger | TS, ISET, CHG, PGOOD, CE |
| GNSS | GNSS_SAFEBOOT (!SAFE), GNSS_RESET_N, GNSS_PPS |

## 8. Board outline, placement and mounting

**65 × 58.5 mm, 2 mm corner radius.** Before, the board was 95 × 75 mm with the carrier's parts laid out beside the plugged boards. Now the three plugged boards are tiled edge to edge, and every carrier part sits underneath them. The board isn't shaped to a shell: the V1-alpha test box gets posts to match (section 12).

Placement as drawn by `layout.py` (top view, origin top-left, x right, y down; renders in `build/`):

| Block | Where | Why |
| --- | --- | --- |
| Connect Kit J1–J4 | Left edge, rows at x = 3.5 and 21.28 (17.78 apart); USB end at the top edge | U.FL cables head down the board to the antennas |
| MAX-M10S J8, J9 | Top right, outline from (26.5, 2.5); its sockets at the breakout's own header positions | Its 8-pin row can't sit closer to the Kit's right-hand socket. The SMA points off the right edge |
| ISM330 J10 | Under the M10S, turned 180° so its pin row is on top | Its M2 standoffs sit at the bottom, clear of the connectors |
| Under the Kit, between its rows | TCA4307 U2, TPS2553 U3, I2C pull-ups, sense dividers, board mounts H1/H2, Kit feed J5 | 11 mm strip of free board the Kit covers anyway |
| Under the M10S | bq24074 U1, each passive beside the pin it serves (`finish_routing.py`), D1/D2 | Short IN → bq24074 → BAT loop; nothing has to wrap round the chip |
| Under the M10S, left | Flash U7 with C12 and R26 (rev A3) | The free board nearest the Kit's spare GPIOs |
| Right edge, between H3 and H4 | Q1, R24, fuel gauge U6, C10, C11, R25 (rev A3) | On the way from the harness to the charger, beside the M10S's I2C socket |
| Under the ISM330 | ESD U4, U5 and the harness INT resistors | Right behind the bottom-edge ports |
| Right edge, beside the ISM330 | Harness J13 | The one column the plugged boards leave free |
| Bottom edge | Cues J11, J12 and panels J6, all low JST-SH | The bottom band is only as deep as an SH socket (6.6 mm) |
| Top edge | Spare Qwiic J7 | |
| Bottom side | 33 test pads on a 5 × 3.6 mm grid, the title, the harness pinout | One pogo fixture from below |

`build/carrier_assembled_top.png` renders the same board with the three plugged boards outlined. The free board left over is a thin strip under the Kit's antenna end, the harness column and the connector band. The size limit is the three boards: the Kit's length sets the height, and the Kit plus the 4 mm socket gap plus the MAX-M10S sets the width.

**Mounting:**
- H1, H2 (M3) are under the Kit, on the centre line between its rows.
- H3, H4 (M3) are the MAX-M10S's two far-corner holes. M3 male-female standoffs there both hold the M10S and screw the carrier down to the box posts.
- H5, H6 are the ISM330's M2 standoffs.
- Assembly order: carrier into the box first, then the plugged boards.

Height above the board: each plugged board sits ~11 mm up (8.5 mm socket + the pins' 2.5 mm plastic spacer), and the tallest part on any of them is ~3.3 mm (the USB-C or SMA). So **~17 mm from the board's top face** (question 7 refines this).

Board: 2 layers, 1.6 mm FR-4, 1 oz, lead-free HASL, green. Ground pour both sides.

**Routing:** Inky (HeyPCB) routed the board; `finish_routing.py` re-placed the charger passives by pin and rerouted that block. The routed board is `pcb/carrier.kicad_pcb`: KiCad DRC is clean at every severity. Power nets are 0.5 mm (0.25 mm fingers on U1's 0.5 mm-pitch pins), 3V3 rails 0.4 mm, signals 0.25 mm. GND is poured both sides with stitching vias, and vias are tented.

## 9. Power budget

Per day, 3.7 V pack side. The Kit's buck-boost is taken as 90 % efficient at these loads (est; [TPS] Fig. 7-2 to 7-4). "Measure" means the multimeter on its µA range in series with the pack. A PPK2 would do it better but is deferred.

| Load | Condition | Current | mAh/day | Source |
| --- | --- | --- | --- | --- |
| MAX-M10S | Continuous tracking, 1 Hz, default GPS+GAL+BDS | 9.5 mA VCC + 2.3 mA V_IO at 3.0 V → ~11.7 mA from the pack | 281 | [UBX] Table 15 |
| | Power-save mode instead | 5 + 2 mA → ~6.9 mA | 166 | [UBX] Table 15 |
| nRF9151 | LTE-M in PSM between reports | µA level | < 1 | Nordic; measure |
| LTE-M reports | Every 15 min | est. 10–30 | 10–30 | Size with Nordic's Online Power Profiler once the interval is set |
| ISM330DHCX board | Accel on, gyro off, plus the Adafruit regulator and power LED | unknown | ? | Measure (question 6) |
| Qwiic Buzzers ×2 | Unpowered between cues (EXT_3V3 off) | 0 idle | ~0 | Cue current only while sounding |
| Connect Kit overhead | Interface MCU, BQ25180, TPS63901, LEDs | unknown | ? | Measure (question 6) |
| bq24074 | No input (night) | 4.3 µA typ | 0.1 | [BQ] 8.5 IBAT(PDWN) |
| TCA4307 | Disabled between uses | 10 µA typ | 0.2 | [TCA] 5.5; ~2.5 mA while enabled, so firmware enables it only to cue or read the pack |
| Dividers | VBAT 2 MΩ | 2.1 µA | 0.05 | |
| MAX17260 | Active, ModelGauge m5 | 5.1 µA typ | 0.12 | [MAX] (rev A3) |
| W25Q128JV | Power-down between writes (10 µA if left in standby) | 1 µA typ | 0.02 | [W25Q] ICC2 (rev A3) |
| **Known total** | GNSS continuous | | **~300** + unknowns | |

Every unknown mA running all the time adds 24 mAh/day.

**Storage:** 6600 mAh, about 5,600 usable from 4.2 V down to a 3.4 V firmware cutoff (est): **~19 days without sun** at 300 mAh/day. V1's 60-day target needs the GNSS averaging ≤ ~3 mA, meaning power-save mode, or GNSS duty-cycled when the animal is far from the fence. That's firmware work, not a board change.

**Harvest:** two P124 in parallel give up to ~0.42–0.46 A in full sun [P124 Isc]. In the draft-1 test box the panels face ±18.7° to either side of the spine [SHELL], so assume ~70 % of flat. Allow another 90 % for dirt and heat: ~0.28 A × peak-sun-hours. Middle Tennessee is roughly 2.5 (Dec) to 5 (Jun) peak sun hours: **~700 mAh/day in winter, ~1,400 mAh/day in summer.** That's 2–4 × the known load, before shade, hair and animals lying down. Firmware logs the real harvest from ISET_SENSE and VIN_SENSE.

## 10. Parts (JLCPCB/LCSC)

From JLCPCB's parts search, 2026-09-26; rev A3 parts and the charger's stock rechecked 2026-09-27. Stock is JLCPCB assembly stock on those days. The numbers are also in `schematic.py` and end up as footprint fields for the BOM.

| Part | LCSC | MPN | Class | Stock |
| --- | --- | --- | --- | --- |
| bq24074 (U1) | C54313 | BQ24074RGTR | Extended | **795** on 2026-09-27 (816 the day before): recheck on order day |
| MAX17260 fuel gauge (U6) | C5280558 | MAX17260SETD+T | Extended | **0 at JLCPCB and LCSC** (C350946, the non-reel listing, also 0). Order through JLCPCB's Global Sourcing (from DigiKey/Mouser), or leave it unfitted: the board runs without it, since R24 carries the current |
| W25Q128JV flash (U7) | C97521 | W25Q128JVSIQ | **Basic** | 59,376 |
| AO3401A P-FET (Q1) | C15127 | AO3401A | **Basic** | 884,323 |
| 10 mΩ 1 % 0805 sense (R24) | C104574 | RALEC RTT05R010FTP | Extended (no Basic 10 mΩ) | 3,931 |
| TCA4307 (U2) | C880333 | TCA4307DGKR | Extended | 2,735 |
| TPS2553 (U3) | C55266 | TPS2553DBVR | Extended | 59,681 |
| ESD (U4, U5) | C7519 | USBLC6-2SC6 (ST) | Extended | 44,218 |
| Schottky (D1, D2) | C8598 | B5819W SL | **Basic** | 493,921 |
| Kit sockets 1 × 10 (J1–J4) | C46635846 | HX PM2.54-1x10P TP H8.5-YQ | Extended | 425 |
| M10S sockets 1 × 8, 1 × 4 (J8, J9) | C46635844, C46635840 | HX PM2.54 H8.5 | Extended | 5,136, 5,201 |
| IMU socket 1 × 9 (J10) | C46635845 | HX PM2.54-1x9P TP H8.5-YQ | Extended | 293 |
| SH 3-pin R/A (J6) | C160403 | SM03B-SRSS-TB | Extended | 24,905 |
| PH 8-pin R/A (J13) | C265121 | S8B-PH-SM4-TB | Extended | 19,343 |
| SH 4-pin R/A (J7, J11, J12) | C160404 | SM04B-SRSS-TB | Extended | 30,694 |
| 100 k, 10 k, 4.7 k, 1 M, 200 k, 1 k, 68 k 0603 | C25803, C25804, C23162, C22935, C25811, C21190, C23231 | UNI-ROYAL 0603WAF | Basic | |
| 10 µF 25 V 0805 | C15850 | CL21A106KAYNNNE | Basic | |
| 100 nF, 10 nF, 1 µF (50 V), 470 nF 0603 | C14663, C57112, C15849, C1623 | | Basic | |

Not fitted: J5 (holes), the 10 kΩ TS resistor (fit only to charge with no NTC), the test pads. Every Extended part adds a small setup fee per unique part at JLCPCB; this board has 16 of them (rev A3: three odd resistor values gone, the gauge and its sense resistor added).

`jlc_files.py` writes JLCPCB's BOM and placement files. For every part it fetches JLCPCB's own footprint and computes the rotation from the pads, rather than a rotation table (section 11, question 12).

The Adafruit 4755 charger board we bought is no longer needed in the collar. It stays a bench reference and a fallback.

## 11. Open questions for Cody

Decided 2026-09-26: rectangle board (was question 1); the harness carries the battery, not 5 V (replaces question 2).

To buy when you're ready (not ordered):
1. **A second SparkFun Qwiic Buzzer** (BOB-24474) and **two Qwiic cables, 200–500 mm**, for the ear pods.
2. **M8 8-pin harness:** a high-flex PUR female-to-male cordset and two panel-mount sockets with leads (one on the box, one on the bottom module). Length once the bottom module is drawn (section 12).
3. Pre-crimped pigtails: JST-SH 3-pin ×1 (panels); JST-PH 8-pin ×2 (harness, and a bench lead to the pack and NTC).

Bench checks when parts arrive:
4. **Pinouts against silkscreen:** the ISM330's 9-pin order (VIN, 3Vo, GND, SCL, SDA, DO, CS, INT1, INT2); the battery pack's JST-PH polarity; the 1.25 mm pigtail's red wire against the `+` on the Kit's J2.
5. **Cut the I2C pull-up jumpers** on the MAX-M10S and both buzzers, and the power-LED jumpers on the M10S and the ISM330.
6. **Idle current**, multimeter in series with the pack: the Kit alone with USB unplugged, then plus the IMU. Those numbers fill the gaps in section 9.
7. **Heights with calipers:** the MAX-M10S from PCB to the top of the SMA, the Kit's male pins below its PCB (spacer and pin length), a female socket's height.
8. **Buzzer loudness from an ear pod:** dB at 1 m with a phone app. It decides piezo or not for the integrated board.

Before ordering:
9. ~~The hanxia sockets' pad stagger~~ **Done 2026-09-27:** the hanxia drawing gives no land pattern. JLCPCB's own footprints for all four sizes (1 × 4, 8, 9, 10) are the mirror of KiCad's `Pin1Left`, so rev A3 uses `Pin1Right`, which matches them exactly. The drawing confirms the 1 × 10 body is 25.40 mm, so two butt into a 1 × 20 at 2.54 mm pitch. When the first boards come back, check that each socket sits flat with every leg on a pad before soldering the Kit on.
10. ~~The bq24074's land pattern~~ **Done:** TI lists the bq24074 in RGT0016C. Its example land pattern (1.68 mm thermal pad, 0.24 × 0.6 mm pads on 2.8 mm centres) matches the KiCad footprint; KiCad's pads reach a little further out (0.825 mm), the usual IPC toe. TI asks for vias in the thermal pad to be filled or tented. Ours are open 0.3 mm vias: a little solder may wick, which is fine for the alpha.
12. **Paper fit test** (`fit_test.py` → `build/carrier-fit-test.pdf`): print at 100 %, check the 50 mm bar, and lay the Kit, MAX-M10S and ISM330 on it. Every header pin should land in a circle.
13. **JLCPCB's placement preview:** upload `build/fab/carrier-gerbers.zip`, `carrier-BOM.csv` and `carrier-CPL.csv` for a quote (uploading orders nothing). In the preview, check that pin 1 of U1, U2, U3, U4, U5, U6, U7 and Q1 sits on the pin-1 pad, and that D1/D2's cathode band faces the CHG_IN side.
14. **MAX17260 stock:** zero at JLCPCB on 2026-09-27. Choose Global Sourcing (JLCPCB buys it from DigiKey or Mouser, adding days and a fee) or leave U6 off the first order.

Not needed now:
11. The Kit's USB VBUS could feed the charger for bench charging. Left out: a diode on VBUS leaks back at high temperature and can wake the Kit's own charger. Bench-charge through J_SOLA with the bench supply at 6 V, 0.5 A limit instead.
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

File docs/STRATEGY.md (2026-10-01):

# Product strategy

Decided 2026-09-26.

## Three layers

| Layer | What | Open? |
| --- | --- | --- |
| **OpenCollar** | Off-the-shelf collar: published design, parts list, firmware. Sold assembled, also buildable DIY | Fully open |
| **Proprietary collar** (name TBD) | Our own engineered collar for farmers who want the best: custom hardware, better GNSS, battery, durability, pulse | Closed hardware and firmware, **open device API** |
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

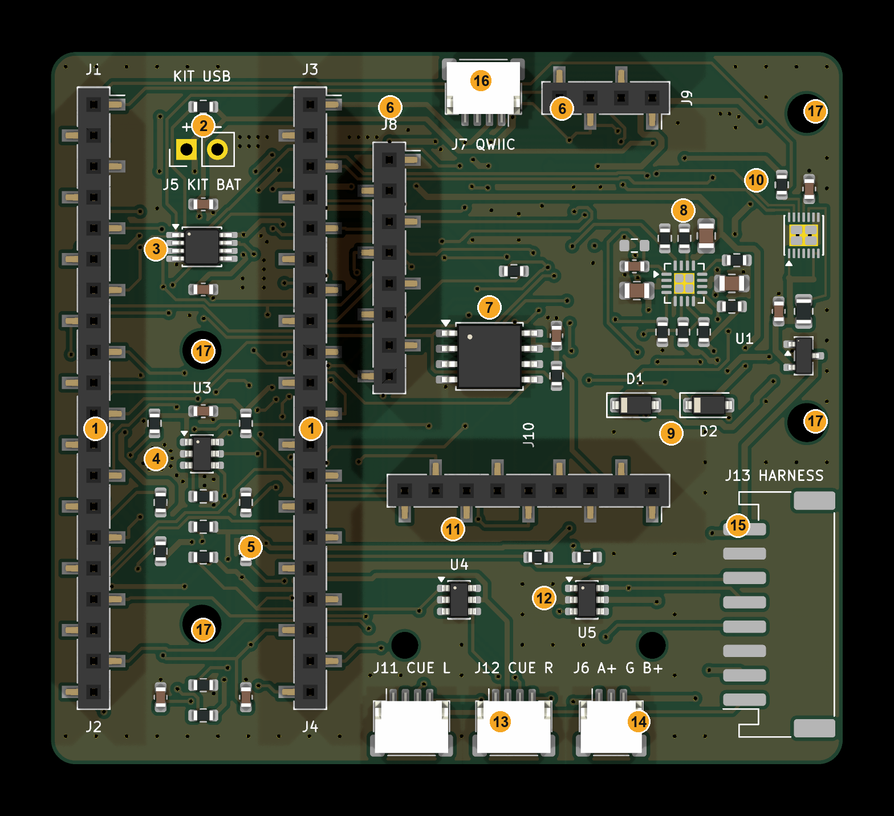
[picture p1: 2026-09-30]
docs/images/carrier/carrier-labelled.png

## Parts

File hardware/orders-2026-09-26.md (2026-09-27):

# Prototype orders, 2026-09-26

| Vendor | Order | Items | Parts | Shipping | Tax / other | Total |
| --- | --- | --- | --- | --- | --- | --- |
| DigiKey | SO 101875374 | MAX-M10S breakout, M6 vent | 49.26 | 8.49 | 5.67 + 0.37 tariff | 63.79 |
| Adafruit | 3751847-9911796966 | 9 lines (see `prototype-cart.md`) | 98.60 | 18.95 | 11.46 | 129.01 |
| Voltaic | 100066117 | 2 × P124 panel | 28.00 | 13.57 | 0 | 41.57 |
| Heritage Animal Health | 20266 | 48" blue neck strap | 23.10 | 10.95 | 0 | 34.05 |
| Hologram | H215420 | Hyper eUICC SIM | 3.00 | 7.50 | 0 | 10.50 (0 charged, promo) |
| Amazon | 112-4704164-9521866 | 1.25 mm leads, heat shrink, silicone wire, M3 screws | | | | 50.44 |
| Amazon | 112-2245515-4903446 | 2 mm O-ring cord (arrives Oct 5) | | | | 16.89 |
| Amazon | (tools) | 10 tools (see `tools.md`) | 192.90 | | | 192.90 + tax |

**Charged: $335.75** ($346.25 before the Hologram promo). Parts $260.31; the rest is shipping and tax. Tools add $192.90 plus tax.

Everything ships to Columbia, TN. Amazon receipts go to a different email address.

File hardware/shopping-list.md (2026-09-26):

# Shopping list, in stages

> The current, simplified order for the first prototype is in `prototype-cart.md`. This staged list is the longer-term plan.

Each stage unlocks the next. Prices are rough.

**Strategy: build one good collar first.** One board can run the nRF9151's built-in GPS and a MAX-M10S at the same time, so GPS comparisons happen side by side on a single collar. Buy multiples only when the design is proven and we need units for the pilot.

## Stage 1: unblock the bench and start playing with GPS (order today)

Goal: V0 end to end (GPS → geofence → buzzer → LTE), plus the first GNSS comparisons against the nRF9151.

| Item | Qty | Why | Approx. |
| --- | --- | --- | --- |
| Nano-SIM with LTE-M data (Hologram Hyper or Onomondo) | 1 | Telemetry, boundary download, A-GNSS | $5 + ~$2/mo |
| SparkFun Qwiic Cable, Female Jumper 4-pin (PRT-14988) | 2 | Qwiic breakouts to the nRF9151 header pins | $2 each |
| SparkFun Qwiic cable kit (assorted lengths) | 1 | Chaining GNSS, IMU and buzzer | $10 |
| MX1.25-2P battery pigtails / JST-PH → MX1.25 adapters | 2 | The board's battery socket is 1.25 mm | $8 |
| **u-blox MAX-M10S breakout** (SparkFun Qwiic) | 1 | V1 GNSS candidate, four constellations. Runs alongside the built-in GPS for side-by-side logs | $45 |
| 25 × 25 mm active L1 patch, U.FL | 1 | V1 antenna size, for the M10S | $10–15 |
| U.FL ↔ SMA pigtails | 2 | Swapping antennas between boards | $10 |
| Copper-clad board, ~70 × 70 mm | 1 | Ground planes under the patches | $10 |
| Qwiic IMU (LSM6DSO or ISM330DHCX) | 1 | Motion-gated fixes, rotation logging | $15–30 |
| USB-C data cables | 1 | Flashing and logs | $15 |

**Stage 1 total: ~$150–200**

**Later, only if the M10S isn't good enough:** a dual-band L1/L5 receiver (MAX-F10S / NEO-F10N, $60–90) with a dual-band antenna ($20–40).

## Stage 2: measure power and prove the solar + LiFePO4 power path

Goal: real numbers for the energy budget before the battery is sized.

| Item | Qty | Why | Approx. |
| --- | --- | --- | --- |
| Nordic Power Profiler Kit II (PPK2) | 1 | Current per GPS fix, per LTE report, in sleep | $100 |
| Multimeter (if you don't have a good one) | 1 | Polarity, voltages | $25–40 |
| Solar charger board with MPPT and LiFePO4 support (TI BQ25798 evaluation board or equivalent) | 1 | The V1 charger, on the bench | $50–150 |
| ETFE mini solar panels, 0.8–1 W, ~110 × 70 mm | 2 | Either side of the GNSS patch | $10 each |
| 26650 LiFePO4 cells, 3.2 V ~3.5 Ah | 3 | Two for the top unit + one spare | $6 each |
| 26650 cell holders / nickel strip + small spot-weld kit (or pre-built 2P packs) | 1 | Assembling packs | $30–60 |
| Small LiFePO4 protection boards (1S) | 2 | Safety on every pack | $3 each |

**Stage 2 total: ~$230–350**

## Stage 3: the V1-alpha collar (dev board in a printed shell)

Goal: one wearable collar. Shell printed by our fabrication partner.

| Item | Qty | Why | Approx. |
| --- | --- | --- | --- |
| **Printed parts from our fabrication partner**: top unit shells, bay cradles, ballast module shells, one camera module | 1 set (plus a spare top unit shell) | The enclosure | Filament/resin + printing time |
| Print material: ASA (UV-stable) or PA12, per the printer's capabilities | as needed | Outdoor-rated shells | $40–80 |
| Silicone O-ring cord kit + cyanoacrylate for joining, or pre-sized O-rings once dimensions are set | 1 | Sealing | $20 |
| Adhesive ePTFE vent patches (Gore-style) | 10 | Pressure equalization; acoustic vent for the buzzer | $15 |
| Stainless steel M3 screws + brass heat-set inserts kit | 1 | Assembly | $25 |
| 50 mm polyester webbing + cam/side-release buckles, stainless hardware | 1 collar | Strap | $15 |
| Ultra-flexible silicone wire, 24–26 AWG, 4 colours | 1 set | Wired strap conductors | $20 |
| IP68 4-pin circular connectors (M8 or similar), male + female pairs | 2 pairs + 1 spare | Strap ↔ top unit and strap ↔ bay | $8–15 per pair |
| Steel or zinc ballast blanks, 450–650 g | 1 | Ballast module | $10 |
| Piezo transducer, sealed, ~95 dB | 1 | Louder, waterproof cue (vs. the Qwiic buzzer) | $5 each |
| Neodymium magnet + hall sensor breakout | 1 | Magnet power-on | $5 each |

**Stage 3 total: ~$250–350** (plus printing)

## Stage 4: camera module

Goal: one camera collar for the pilot.

| Item | Qty | Why | Approx. |
| --- | --- | --- | --- |
| GoPro HERO (base model) | 1 | Camera module; open API for later collar control | $200 |
| Compact 10,000 mAh USB-C power bank | 1 | Camera power, doubles as module mass | $25 |
| GoPro two-prong mount buckles + thumbscrews | 1 set | Mount interface | $10 |
| High-endurance microSD card, 128 GB | 1 | Long recordings | $30 |
| Replaceable clear lens protectors | 1 pack | Mud and scratches | $10 |

**Stage 4 total: ~$250–280**

## Stage 5: field testing

| Item | Qty | Why | Approx. |
| --- | --- | --- | --- |
| IP67 project box | 1 | Backpack tests before shells are ready | $20 |
| Waterproof USB power bank | 1 | Long outdoor runs | $40 |
| Handheld GPS or phone with RTK/survey app access, or a known survey marker nearby | 1 | Reference points to measure real accuracy (CEP) against | Varies |

## All stages

**~$900–1,200** for one complete collar with camera, not counting printing or monthly data. More units come after the design is proven, for the pilot at the pilot farm.

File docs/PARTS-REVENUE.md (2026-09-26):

# Making money from the open parts list

Two options: affiliate links on the published parts list, and kits we sell. Researched 2026-09-26.

## Affiliate programs for the vendors on our list

| Vendor | Program | Rate | Notes |
| --- | --- | --- | --- |
| SparkFun | [Yes](https://www.sparkfun.com/affiliate-program) | **10 %**, SparkFun Original products only | Our IMU, Qwiic cables and MAX-M10S board are SparkFun Originals (the M10S is backordered there right now; we're buying it at DigiKey) |
| Amazon | Associates | ~2.5–3 % | Electronics 2.5 %, industrial supplies 3 %. Rates change quarterly |
| GoPro | [Yes](https://gopro.com/en/us/legal/gopro-affiliate-program) | 3 % | 30-day cookie |
| Adafruit | [No](https://blog.adafruit.com/2009/09/14/adafruit-has-never-and-will-never-do-any-affiliate-programs-period/) | — | Publicly refuses affiliate programs |
| DigiKey | Unclear | Low if it exists | No rate published; needs a direct inquiry |
| TI, Voltaic, Pololu, United Lithium, K&J, Heritage | Not found | — | Worth asking Voltaic and Pololu directly |

### What that earns

A collar build is roughly $450–550 in parts (excluding test gear like the PPK2).

| Source | Qualifying spend | Commission |
| --- | --- | --- |
| SparkFun Originals (IMU, cables, MAX-M10S if bought at SparkFun) | ~$90 | ~$9 |
| Amazon | ~$60 | ~$2 |
| GoPro (camera builds only) | ~$220 | ~$7 |
| **Per build** | | **~$10–20** |

So affiliate income is about **$10–20 per collar built**: fine as a bonus, not a business until thousands of people build collars. Routing more parts through SparkFun (which sells many third-party parts, but pays only on its own) helps a little.

**Rules:** US law (FTC) requires a clear affiliate disclosure next to the links. The open hardware community is sensitive to hidden affiliate links, so disclose plainly at the top of the parts list and keep a plain, non-affiliate link for every part.

## Kits

Buy parts in volume, sell complete kits. This is where the money is, and it's a better experience for builders: one box instead of twelve orders.

### Tiers

| Kit | What's in it | Who it's for |
| --- | --- | --- |
| **Electronics kit** | Every board and module, pre-flashed firmware, harness pre-made, cells shipped separately | Builders who print their own shell |
| **Complete kit** | Electronics kit + printed shell set + strap + hardware | Farmers and tinkerers who want to assemble but not source or print |
| **Assembled collar** | Built, tested, ready to strap on | Farmers who just want a collar (this becomes the sold OpenCollar) |

### Rough margins (breakout-board version, 100-kit batch)

- Retail cost to source it yourself: ~$450–550 (collar, no camera).
- Our cost buying 100 kits' worth: typically 20–35 % less through distributor price breaks and direct buys, plus our labour to flash, test and pack.
- **Sell at or slightly below the cost of sourcing it yourself** and the margin is roughly **$100–200 per kit**, about 10× the affiliate income.
- Once V1-beta has its own custom board, the kit gets much cheaper to make (the breakout boards and eval kits are most of the cost), and the margin grows.

### Things to sort out before selling kits

- **Batteries:** lithium cells need UN38.3-certified cells, hazmat labelling and restricted shipping methods. Simplest start: kits exclude cells, with a link to buy them, or ship cells via a supplier who handles it.
- **Radio certification:** kits built from pre-certified modules (nRF9151, u-blox) are generally fine to sell as kits; an assembled product with our own board needs FCC certification.
- **Support and returns:** a kit business is also a support business. Good build docs reduce this a lot.
- **Liability:** once the pulse module exists, stimulus kits need extra care (instructions, warnings, welfare guidance).

## Recommendation

Do both, in order:
1. **Now:** publish the parts list with affiliate links where they exist (SparkFun first), plainly disclosed, plus plain links.
2. **After the prototype works:** sell electronics and complete kits from a first batch of ~25–100.
3. **After V1-beta:** assembled collars on the custom board become the main product; kits stay for builders.

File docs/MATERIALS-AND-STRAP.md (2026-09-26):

# Materials and strap

The CAD will be open source so anyone can print the collar. That means designing for printers people actually have, in materials that survive a cow.

## Approach: buy the strap, print the modules

Don't print the strap. Commercial cattle neck straps (~50 mm woven nylon or polyester, stainless buckle, adjustable) are cheap, proven on animals, and available from any livestock supplier. We print only the rigid parts that mount to it:

- **Top unit**: the strap passes through slots moulded into its underside and is clamped with a printed bar and screws.
- **Bay cradle**: same slot-and-clamp mount at the bottom of the strap; modules lock into it with thumbscrews.
- **Strap wiring**: an off-the-shelf high-flex M8 4-pin cordset (industrial robot cable, IP67/68) plugs into sockets on the top unit and the bay and runs along the strap's non-adjusting side in printed TPU clips. See `BOTTOM-BAY.md`.

Anyone rebuilding the collar buys a standard strap and prints the rest.

## What to print each part in

| Part | Material | Why |
| --- | --- | --- |
| Top unit shell and lid | **ASA** (desktop FDM) or **PA12** (MJF/SLS service) | Rigid, UV-stable, handles heat. ASA prints on most enclosed desktop printers; PA12 from a print service or a lab machine is tougher and needs no supports |
| Bay cradle and module shells | ASA or PA12 | Takes knocks from the ground, posts and other cattle |
| Strap clamps, bumpers, strap clips, cable strain reliefs | **TPU 95A** (flexible) | Absorbs impact, grips the strap, won't crack |
| Seals | **Silicone O-rings** (bought), not printed | Printed gaskets don't seal reliably over time |

### Why not PLA or PETG

- **PLA** softens around 55–60 °C. A collar in July sun gets hotter than that, so PLA creeps and deforms. It also goes brittle outdoors.
- **PETG** handles heat better but yellows and weakens in UV over a season.
- **ASA** is essentially outdoor-grade ABS: built for sun and weather.
- **Nylon with carbon fibre** (PA-CF) is stronger still, but absorbs moisture, which makes it swell and weaken in wet pastures unless sealed. Not a first choice.

### Colour

Light colours (white, light grey, tan). A dark shell in full sun runs much hotter, which is bad for the battery (LiFePO4 is happiest below ~45 °C), the electronics, and the material.

## Printing guidelines for the open design

- **Walls:** at least 2.5–3 mm (6 perimeters at 0.4 mm), with ribs rather than solid thickness.
- **Infill:** 40 % or more in load-bearing areas; 100 % around screw bosses and the strap slots.
- **Screws:** brass heat-set inserts for every screw that gets opened more than once.
- **Sealing:** O-ring groove in the lid, designed for the printer's tolerance; sealed flat faces sanded or vapour-smoothed where the O-ring sits.
- **Print orientation:** noted per part, so layer lines never run across a load path (for example, strap slots printed so layers wrap around the slot).
- **Test prints:** each release is checked for water (submersion), drops and heat before it's published.

## Questions for the fabrication partner

- Which printers: desktop FDM (which brand, enclosed or not), resin, MJF/SLS?
- Which materials does he already run: ASA, PC, PA12, TPU?
- Build volume (the top unit is roughly 130 × 90 × 45 mm)?
- Can he do heat-set inserts and a submersion test at the lab?

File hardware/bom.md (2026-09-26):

# Bill of materials

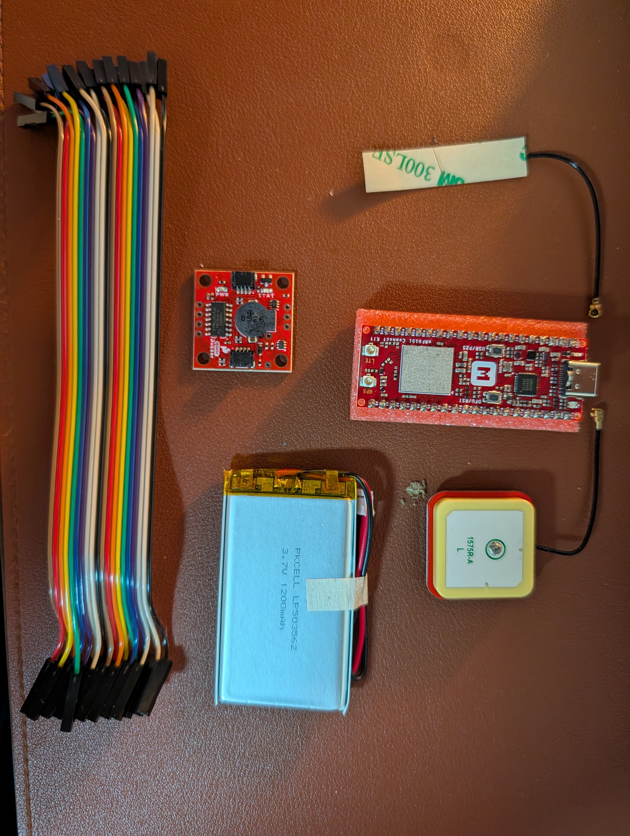
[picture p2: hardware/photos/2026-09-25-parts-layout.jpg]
Parts layout


| Part | Model | Qty | Role | Notes |
| --- | --- | --- | --- | --- |
| Main board | Makerdiary nRF9151 Connect Kit | 1 | MCU + LTE-M/NB-IoT modem + GNSS | nRF9151 SiP (Cortex-M33). nRF52820 interface MCU gives CMSIS-DAP flashing and USB-UART over USB-C. BQ25180 LiPo charger, TPS63901 buck-boost. Nano-SIM slot. U.FL for LTE and GPS. Onboard GNSS LNA, enabled by nRF9151 `COEX0`. Firmware: nRF Connect SDK / Zephyr. |
| LTE antenna | Flexible adhesive antenna, U.FL | 1 | Cellular | 3M 300LSE adhesive backing. Connects to the `LTE` U.FL. |
| GPS antenna | Ceramic patch, 1575R-A, U.FL | 1 | GNSS | Connects to the `GPS` U.FL. Ceramic face points at the sky. |
| Buzzer | SparkFun Qwiic Buzzer (BOB-24474) | 1 | Audio cue | I2C, default address 0x34, 3.3V. ATtiny84 onboard handles tone, volume, duration. Qwiic (JST-SH 4-pin) connectors; 0.1" through-holes have no headers fitted. |
| Battery | PKCELL LP503562, 3.7V 1200mAh LiPo | 1 | Power | 2-wire lead with connector. Polarity must be checked against the board before connecting. |
| Jumper wires | Dupont female-female, ribbon | 1 set | Bench wiring | |

## Still needed

| Part | Why |
| --- | --- |
| Nano-SIM with LTE-M data | Board can't reach the network without one. Hologram, Onomondo, Soracom, or 1NCE. |
| Qwiic to female-jumper cable (SparkFun PRT-14988) or 4-pin 0.1" header + soldering iron | Dupont jumpers can't plug into the buzzer as-is. |
| USB-C data cable | Flashing, serial logs, charging. |

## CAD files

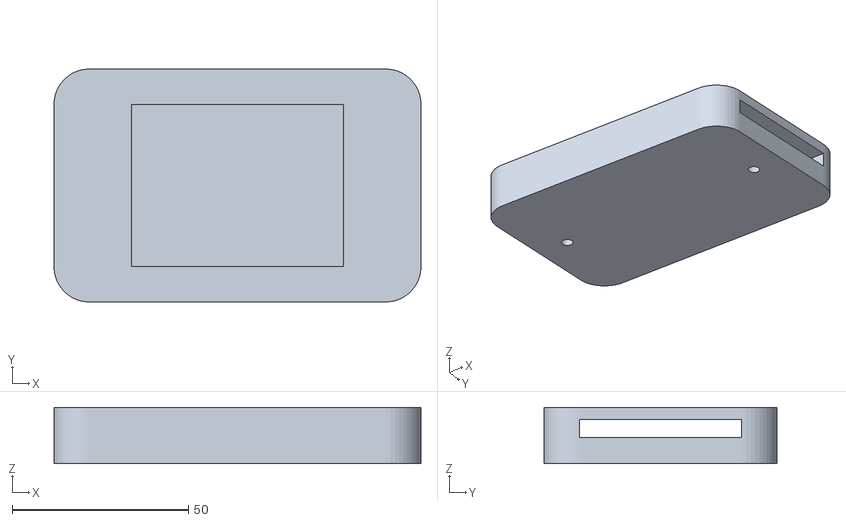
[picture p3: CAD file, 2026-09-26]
mechanical/exports/bay/bay_cradle.stl
104.0 x 66.0 x 16.0

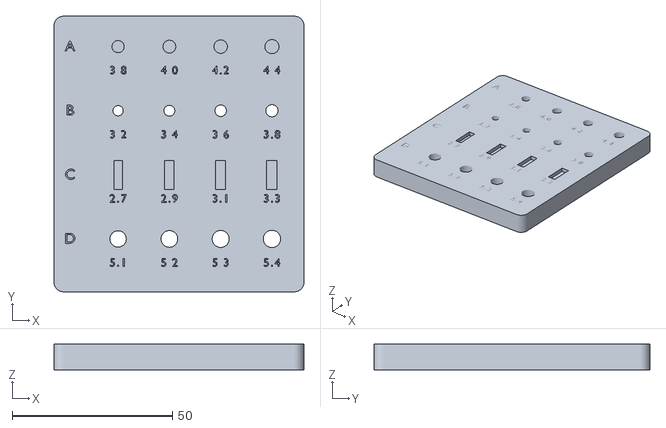
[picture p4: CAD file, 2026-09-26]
mechanical/exports/fit_test/fit_test.stl
78.0 x 86.0 x 8.00

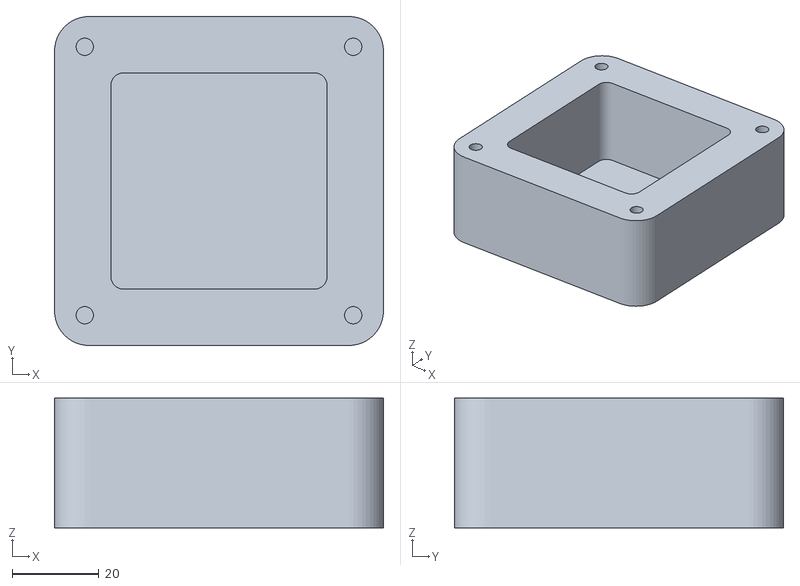
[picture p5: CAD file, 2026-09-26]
mechanical/exports/seal_box/seal_box_box.stl
76.0 x 76.0 x 30.0

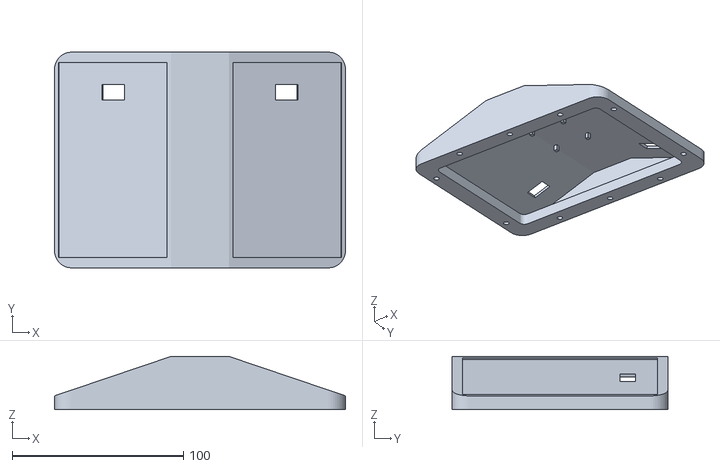
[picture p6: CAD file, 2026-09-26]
mechanical/exports/top_unit/top_unit_lid.stl
170.0 x 126.0 x 31.0

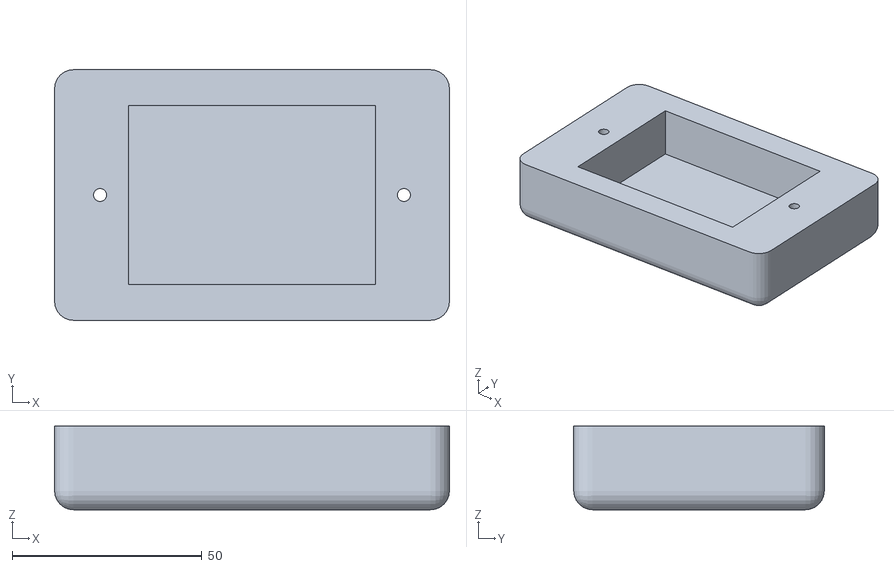
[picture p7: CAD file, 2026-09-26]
mechanical/exports/bay/bay_ballast_module.stl
104.0 x 66.0 x 22.0

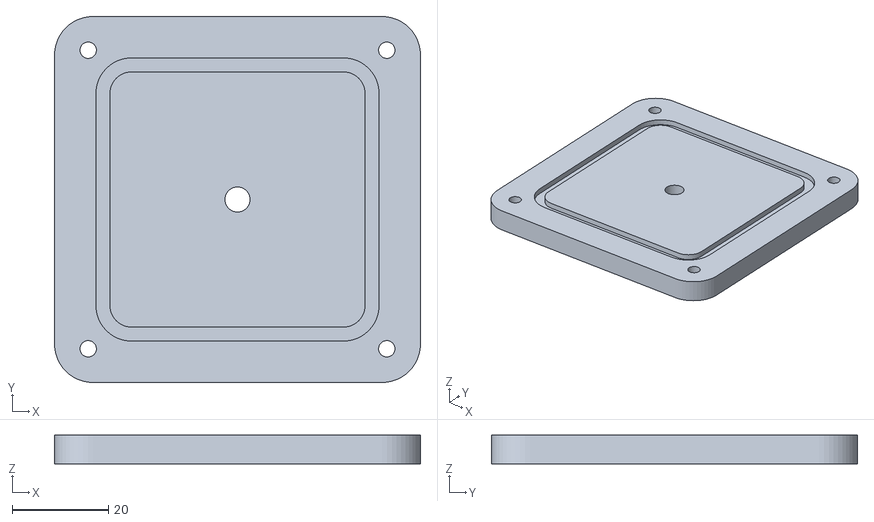
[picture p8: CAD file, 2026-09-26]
mechanical/exports/seal_box/seal_box_lid.stl
76.0 x 76.0 x 6.00

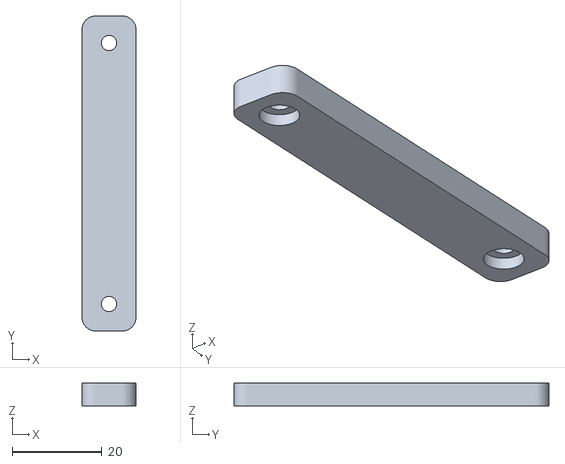
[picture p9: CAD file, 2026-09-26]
mechanical/exports/top_unit/top_unit_clamp_bar.stl
12.0 x 70.0 x 5.00

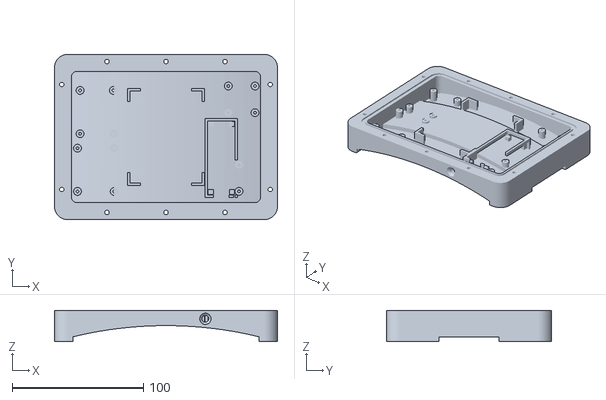
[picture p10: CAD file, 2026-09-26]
mechanical/exports/top_unit/top_unit_base.stl
170.0 x 126.0 x 24.0

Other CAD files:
mechanical/assembly/collar_v1_alpha.blend

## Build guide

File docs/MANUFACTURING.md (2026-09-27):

# Manufacturing 1,000 collars

Written 2026-09-26, before the first prototype is assembled. Estimates, not quotes.

## The one big change: a custom board

The prototype is breakout boards joined by jumper wires. That doesn't scale:

- **Labour:** two to three hours of hand soldering and wiring per collar. 1,000 collars is roughly a year of one person's time.
- **Reliability:** every connector and hand joint is a failure point on an animal that rubs, rolls and gets rained on.
- **Cost:** the breakout boards alone are most of the $260 parts bill.

So the collar becomes **one custom board**, shaped to the shell and assembled by a factory:

- nRF9151 SiP (LTE-M + fence logic) and MAX-M10S (GNSS) as modules, soldered by machine.
- Charger (BQ25798, LiFePO4), IMU, buzzer driver, flash, eSIM, antenna feeds, and connectors to the panels, battery and strap harness, all on the same board.
- **Test pads** on the board so a fixture can flash and test it in seconds.

With that, each collar takes about 15–20 minutes of final assembly instead of hours.

## Who builds what

| Part | Who | Notes |
| --- | --- | --- |
| Board design | Us, with a contract PCB designer to review | The prototype circuit is the reference. Budget $5–20k for outside review and layout help |
| Board assembly (PCBA) | Turnkey assembler: JLCPCB or PCBWay (cheapest), or a US shop like MacroFab (faster to talk to, higher cost) | They buy the parts, build and ship finished boards |
| Shell | MJF/SLS print service (PA12) for the first few hundred; injection moulding after the design freezes | See below |
| Battery packs | A pack maker assembles the LiFePO4 cells with protection and a connector | Must come with UN38.3 test reports for shipping |
| Solar panels | Voltaic (or a panel maker) at volume pricing, with our connector fitted | |
| Straps + harness | Livestock strap supplier; off-the-shelf M8 cordsets | |
| Final assembly, test, pack | **Us**, in a small workspace at first | Keeps quality in our hands while the design is still settling. Move to a contract manufacturer (box build) once stable |

## Shell: print first, mould later

- **Injection moulding:** tooling runs $10–40k per part family (top unit, lid, bay, clamps). The part then costs a dollar or two. It only pays off once the design stops changing.
- **MJF printing in PA12:** no tooling, roughly $15–40 per shell set at a service, and it's tough enough for the field.
- **So:** print the first 100–500, learn from the field, freeze the design, then cut moulds for the rest. The shell must be designed with moulding in mind from the start (draft angles, even walls) so switching doesn't mean a redesign.

## Certification (the long pole)

| What | Why | Rough cost / time |
| --- | --- | --- |
| FCC (US) | Any radio product sold in the US. Using pre-certified radio modules cuts this down a lot, but the finished collar still needs testing | $10–30k, 1–3 months |
| Carrier approval (PTCRB and/or AT&T/Verizon) | Required to run on US LTE-M networks | $15–40k, 2–3 months |
| ISED (Canada), CE (EU) | Only if selling there | Later |
| Battery shipping (UN38.3) | Lithium cells can't ship without it | Comes from the pack maker |
| Stimulus / animal welfare | When the pulse module ships. Some markets restrict it | Check before launch |

Start a pre-scan at a test lab as soon as the first custom boards work, so surprises come early.

### Why each is needed

- **FCC** is legal permission to sell a radio in the US. Anything that transmits needs it, so devices don't interfere with other radios and phone networks. Without it we can't sell or market the collar, and stores and customs increasingly check for an FCC ID.
  - Nordic has already certified the nRF9151. If we follow their antenna and layout rules, we reuse that approval, and the whole collar only needs a smaller test that it doesn't leak radio noise. Departing from their rules (a different antenna, for example) can mean more testing.
  - A few prototypes for our own development and testing are generally fine. The rule bites when we sell.
- **Carrier approval** (PTCRB for AT&T and T-Mobile, Verizon's own program) is permission to stay on the cell network. Carriers only allow certified devices long term, to protect the network from devices that misbehave (reconnecting over and over and flooding a tower, for example).
  - A handful of uncertified collars on a Hologram SIM will likely work. At hundreds or thousands, a carrier can block uncertified devices, and a whole herd's collars would go dark.
  - The nRF9151 and its modem firmware already carry carrier certifications, so a collar built on it usually needs lighter testing than a phone.
- Because we build on pre-certified parts, the real cost may land below the ranges above. A lab quote needs the custom board, so nothing is spent here until then.

## Stages

| Stage | Units | What it proves | Build method |
| --- | --- | --- | --- |
| Prototype | 1 | GPS, fence, cue, physical collar | Breakouts, hand-built (now) |
| Alpha | 5–10 | Same collar on real cattle | Breakouts, hand-built |
| EVT (custom board) | 10–20 | The board works | Turnkey PCBA, printed shells |
| DVT | 50–100 | Field pilot, certification testing, test fixture | Turnkey PCBA, printed shells |
| PVT | 100–200 | The production line works at pace | Full process, first paid customers |
| Production | 1,000 | | Moulded shells once the design is frozen |

Roughly **9–15 months** from a working prototype to 1,000 shipped, with certification and field testing setting the pace.

## Money

- **One-time costs:** board design help ($5–20k), certification ($25–70k), test fixtures ($3–10k), moulds when ready ($10–40k). Roughly **$50–140k**.
- **Per collar at 1,000:** parts and assembly about $110–150, plus $5–8 for packaging and freight.
- **Cash for the run:** about **$150–200k** before the first 1,000 are paid off. Pre-orders with deposits (the reservation page) and the kit business are the natural ways to fund it.

## The end-of-line test (every collar)

1. Fixture flashes firmware and checks the board (power rails, IMU, GNSS, modem) through the test pads.
2. After assembly: leak test (pressure decay through the vent port, or submersion on a sample).
3. Outdoor or GNSS-simulator check that the collar gets a fix, and an LTE-M check-in to our server.
4. Serial number, SIM and device ID recorded against the unit, then packed.

## Next decisions

- When the prototype works: find a PCB designer and get quotes from JLCPCB/PCBWay and one US assembler.
- Pick the test lab and book a pre-scan slot.
- Decide whether final assembly starts in-house (recommended for the first few hundred).

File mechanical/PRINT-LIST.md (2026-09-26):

# OpenCollar V1-alpha: print list

Draft 1, 2026-09-26. Two test prints first, then the collar itself. All parts in **ASA**, light grey or white, 0.2 mm layers, 6 perimeters, 40 % infill (100 % is fine for the small parts). Files are STL in millimetres.

Pictures of the design are in `renders/`; `collar_v1_alpha.blend` opens in Blender 5.x.

## 1. Test prints (please do these first)

| File | Qty | Orientation | What it tells us |
| --- | --- | --- | --- |
| `fit_test.stl` | 1 | Flat, engraved face up | Best hole sizes on your printer: row A M3 heat-set inserts, row B M3 screw clearance, row C 2 mm O-ring cord groove, row D M6 × 0.75 tap drill. Engraved numbers are the designed size |
| `seal_box_box.stl` | 1 | Open side up | Submersion test of the seal the collar uses |
| `seal_box_lid.stl` | 1 | Groove side up | (with the box) |

Seal box: fit 4 inserts, press ~213 mm of 2 mm silicone O-ring cord into the lid groove (superglue the butt joint), tap the centre hole M6 × 0.75 and screw in the vent, close with 4 × M3 × 8 socket-head screws around a dry paper towel. Hold 1 m under water for 30 minutes, then check the towel.

Please send back: the winning size in each fit-test row, whether the box stayed dry, printer and material, and anything that printed badly. The collar files get updated to your sizes before you print them.

## 2. The collar

| File | Qty | Orientation | Notes |
| --- | --- | --- | --- |
| `top_unit_base.stl` | 1 | Underside down, tree supports under the arch | Rim with the O-ring groove faces up |
| `top_unit_lid.stl` | 1 | Rim down, tree supports inside the roof | Solar panels bond into the two recesses |
| `top_unit_clamp_bar.stl` | 2 | Flat | Clamp the strap under each end of the top unit |
| `bay_cradle.stl` | 1 | On its side (a long edge down) | Strap threads through its tunnel; keeps the tunnel roof a short bridge |
| `bay_ballast_module.stl` | 1 | Top face down | Holds the steel ballast slab |

MJF/SLS PA12 is also fine and needs no supports.

### Hardware

| Item | Qty |
| --- | --- |
| M3 × 4 brass heat-set inserts | 16 (10 lid, 4 clamp bars, 2 bay) |
| M3 × 16 socket-head screws, stainless | 10 (lid, from underneath) |
| M3 × 8 button-head screws, stainless | 4 (clamp bars) |
| M3 × 20 knurled thumbscrews, head ≤ 8 mm | 2 (ballast module to cradle) |
| 2 mm silicone O-ring cord | ~500 mm (top unit groove) |
| M6 × 0.75 ePTFE vent (Amphenol VENT-PS2NGY-O8001) | 1, tapped into the base end wall |
| Mild steel flat bar, 64 × 46 × 16 mm | 1 (~370 g ballast) |

### Estimated weight

| | Approx. |
| --- | --- |
| Top unit: printed parts ~220 g + battery, boards, panels, antennas ~280 g | ~500 g |
| Bay: cradle + module ~135 g + steel 370 g | ~505 g |
| Strap | ~100 g |
| **Collar** | **~1.1–1.2 kg** |

### Still open

- Strap length: around the 107 cm neck section we modelled, the loop takes ~1,156 mm of the 48" (1,219 mm) strap, which leaves little for the buckle. Measure the pilot animals' necks; bigger necks need a longer strap.
- Strap thickness is designed at 4 mm until measured; the strap channel, clamp squeeze and bay tunnel follow it.
- A few board heights and antenna sizes aren't published; they're modelled with margin and get checked against the real parts.

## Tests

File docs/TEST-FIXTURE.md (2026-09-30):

# Testing boards: the test fixture, from zero

Written 2026-09-27 for someone who has never done hardware. It covers what a test fixture is, the parts one is made of, what it checks on each board, and what that means for how we design our boards. Prices are typical list prices from memory, to check before buying anything. Nothing here has been ordered.

## 1. Where testing fits

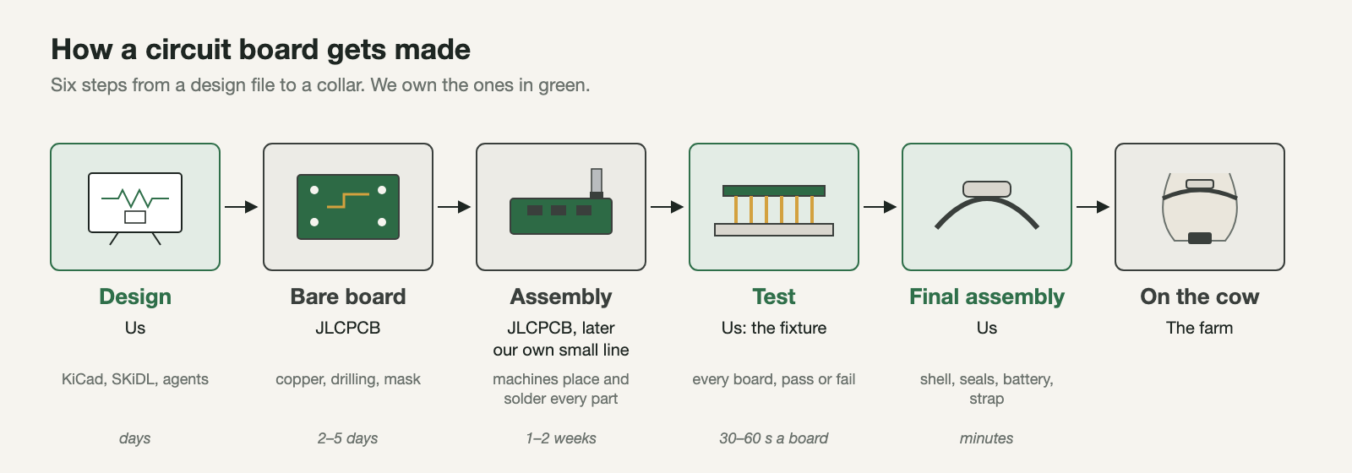
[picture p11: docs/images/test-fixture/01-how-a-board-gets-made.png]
How a circuit board gets made


A board goes through six steps. Two of them happen in factories we rent: JLCPCB makes the bare board and solders the parts on. **Test** is the step where we find out whether each board actually works before it goes into a collar. A board can look perfect and still have one bad solder joint, a chip placed backwards, or a part that leaks a little current and would flatten the battery in a week. The only way to know is to power every board up and check it.

Testing by hand with a multimeter is fine for 5 boards. For 500 it's days of work, and people get tired and miss things. So factories use a **test fixture**: a jig that checks a board in about a minute, the same way every time.

## 2. What a test fixture is

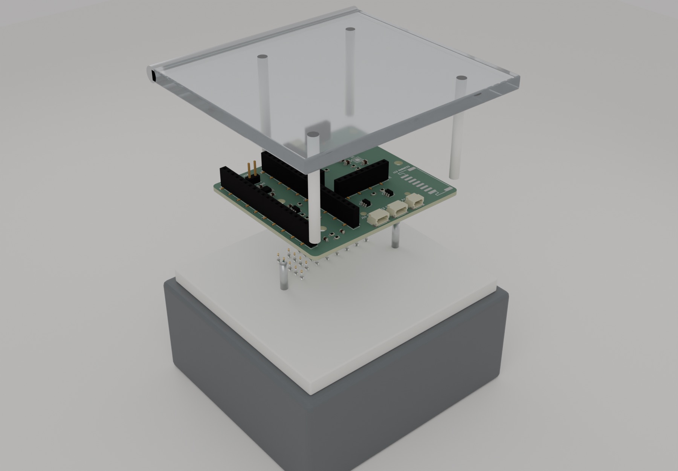
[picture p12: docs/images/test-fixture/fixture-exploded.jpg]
A test fixture, pulled apart


*Our real carrier board above a fixture, pulled apart so you can see the layers. Top to bottom: a clear lid on a hinge, the board, the probe plate with its spring pins, and the base with the wiring.*

It's often called a **bed of nails**. You drop the board onto a plate of spring-loaded pins, close the lid, and the pins press against small bare copper spots on the underside of the board: the **test pads**. Each pin is wired to test equipment. Now a computer can "touch" every important point on the board at once, without anyone holding a probe.

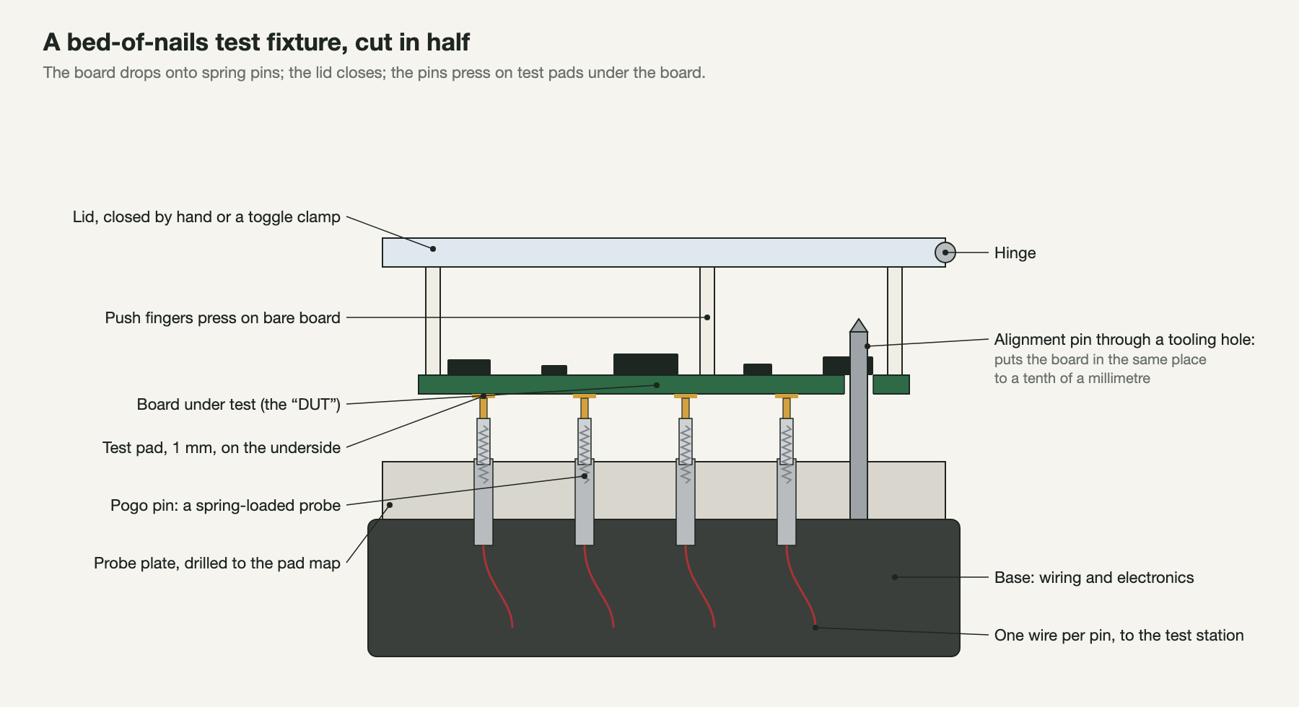
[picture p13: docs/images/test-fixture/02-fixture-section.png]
Cross-section of a fixture


- **The alignment pins** go through holes in the board, so it always lands in exactly the same place and each pin hits its pad.
- **The push fingers** on the lid press the board down onto the pins. They land on bare board, never on parts.
- **The pins are springs**, so small differences in board thickness or flatness don't matter.

## 3. The bed of nails

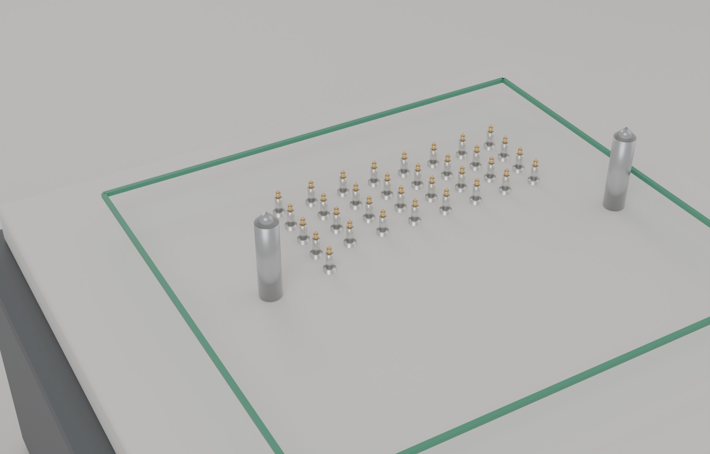
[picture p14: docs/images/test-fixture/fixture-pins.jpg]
The pins on their own


*The probe plate on its own. There's one gold pin under each of our carrier board's 33 test pads, placed from the real board file. The green frame is where the board sits. The two tall steel pins are the alignment pins.*

Each pin is a **pogo pin**:

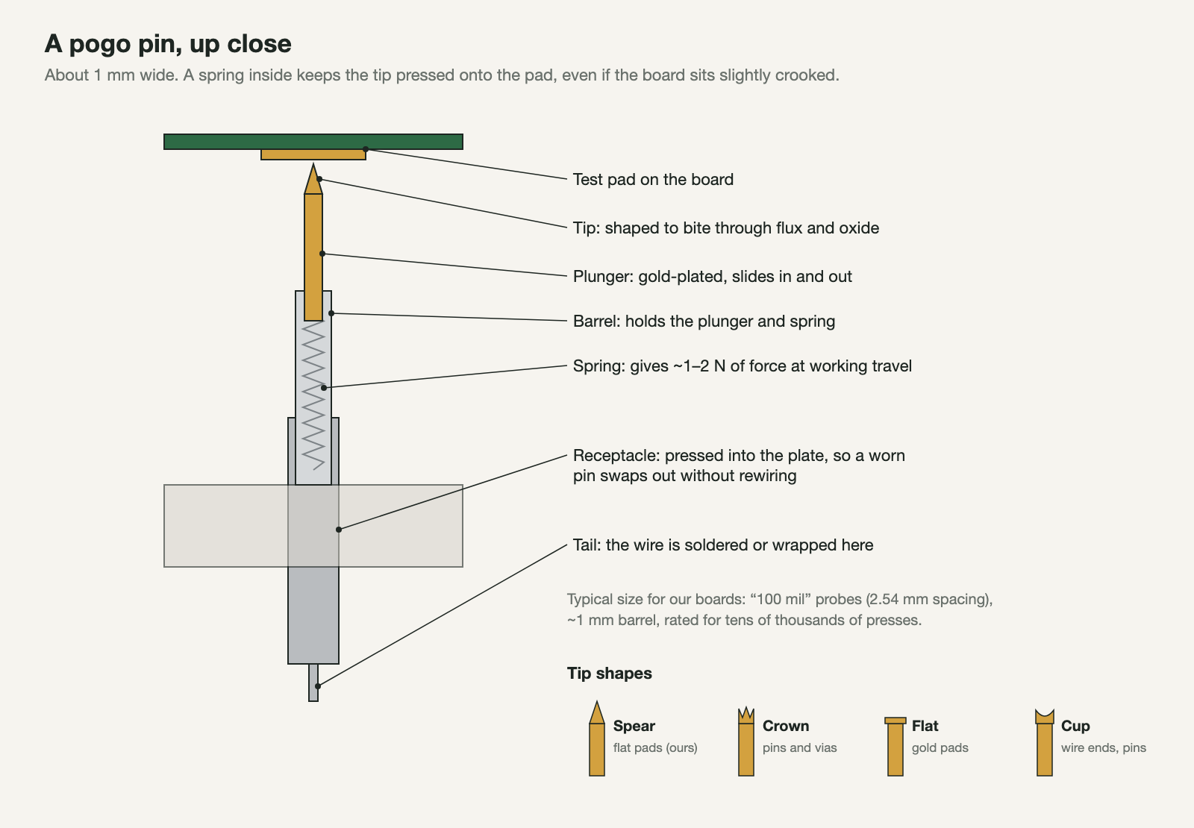
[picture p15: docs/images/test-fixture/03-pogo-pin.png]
A pogo pin up close


| Part | Example | Rough price |
| --- | --- | --- |
| Pogo pins, cheap | Generic "P75" series (e.g. P75-E2, spear tip), 1 mm barrel, 2.54 mm spacing | ~$0.10–0.50 each |
| Pogo pins, good | INGUN GKS-100 series (German fixture maker) | ~$2–5 each |
| Receptacles | Matching sockets pressed into the plate (e.g. R75-2W), so worn pins swap out | ~$0.10–1 each |
| Probe plate | CNC-cut G10 or delrin. **Or order it as a circuit board from JLCPCB**: its drill file is just our test-pad positions | ~$10–50 |
| Lid clamp | A toggle clamp (DE-STA-CO 202-U or a generic copy) or a simple hinge | ~$10–30 |
| Frame | 3D printed on the Ender, or laser-cut | cents to ~$50 |

## 4. The test station: what the fixture plugs into

The fixture itself is just pins and wires. The checking is done by a small set of instruments, all driven by one computer running a test script:

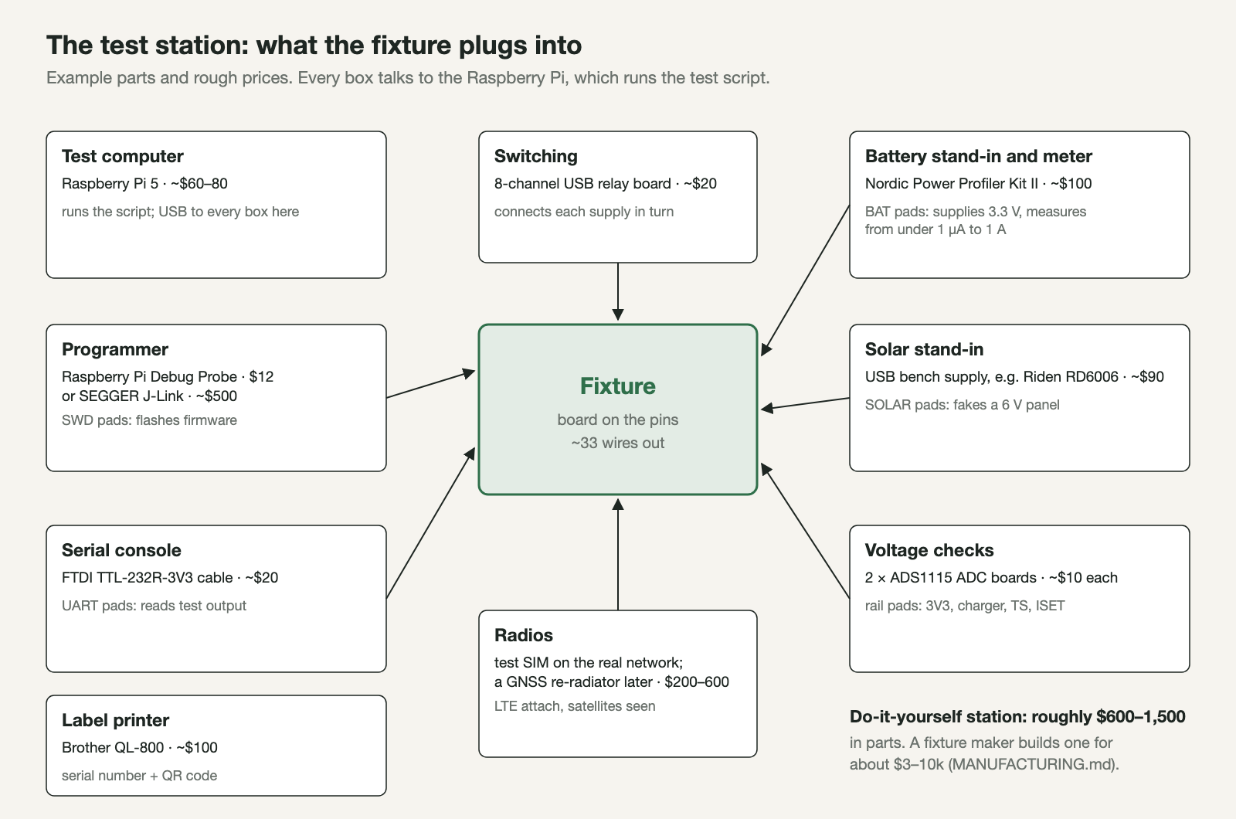
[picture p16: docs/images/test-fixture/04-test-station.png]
The test station


| Job | Example part | Rough price | What it does |
| --- | --- | --- | --- |
| Test computer | Raspberry Pi 5 | ~$60–80 | Runs the test script, talks to every instrument over USB, stores the results |
| Programmer | Raspberry Pi Debug Probe | $12 | Loads firmware through the board's SWD pads. It's the same kind of programmer (CMSIS-DAP) we already use to flash the Connect Kit with pyOCD |
| | or SEGGER J-Link | ~$500 | The industry standard; Nordic's tools use it |
| Battery stand-in and current meter | Nordic Power Profiler Kit II | ~$100 | Pretends to be the battery (it supplies 0.8–5 V) and measures current from under a microamp up to 1 A. It's also on our deferred-parts list for power measurements anyway |
| Solar stand-in | A USB-controlled bench supply, e.g. Riden RD6006 | ~$90 | Pretends to be the solar panels: 6 V, current-limited |
| Voltage checks | 2 × ADS1115 ADC boards | ~$10 each | Reads the voltage on each power rail pad |
| Switching | 8-channel USB relay board | ~$20 | Connects and disconnects the supplies at each step |
| Serial console | FTDI TTL-232R-3V3 cable | ~$20 | Reads the messages the board's firmware prints |
| Radios | A test SIM on the real LTE network; later a GNSS re-radiator (an outdoor antenna that re-broadcasts satellite signals indoors) | $0; $200–600 | Checks the modem connects and the GNSS sees satellites |
| Label printer | Brother QL-800 | ~$100 | Prints a serial-number label with a QR code |

**About $600–1,500 in parts for a station we build ourselves.** A fixture company would build one for about $3–10k (`MANUFACTURING.md`). We'd build the first one ourselves: it's a good project, and the same station serves every future board.

## 5. One board through the fixture

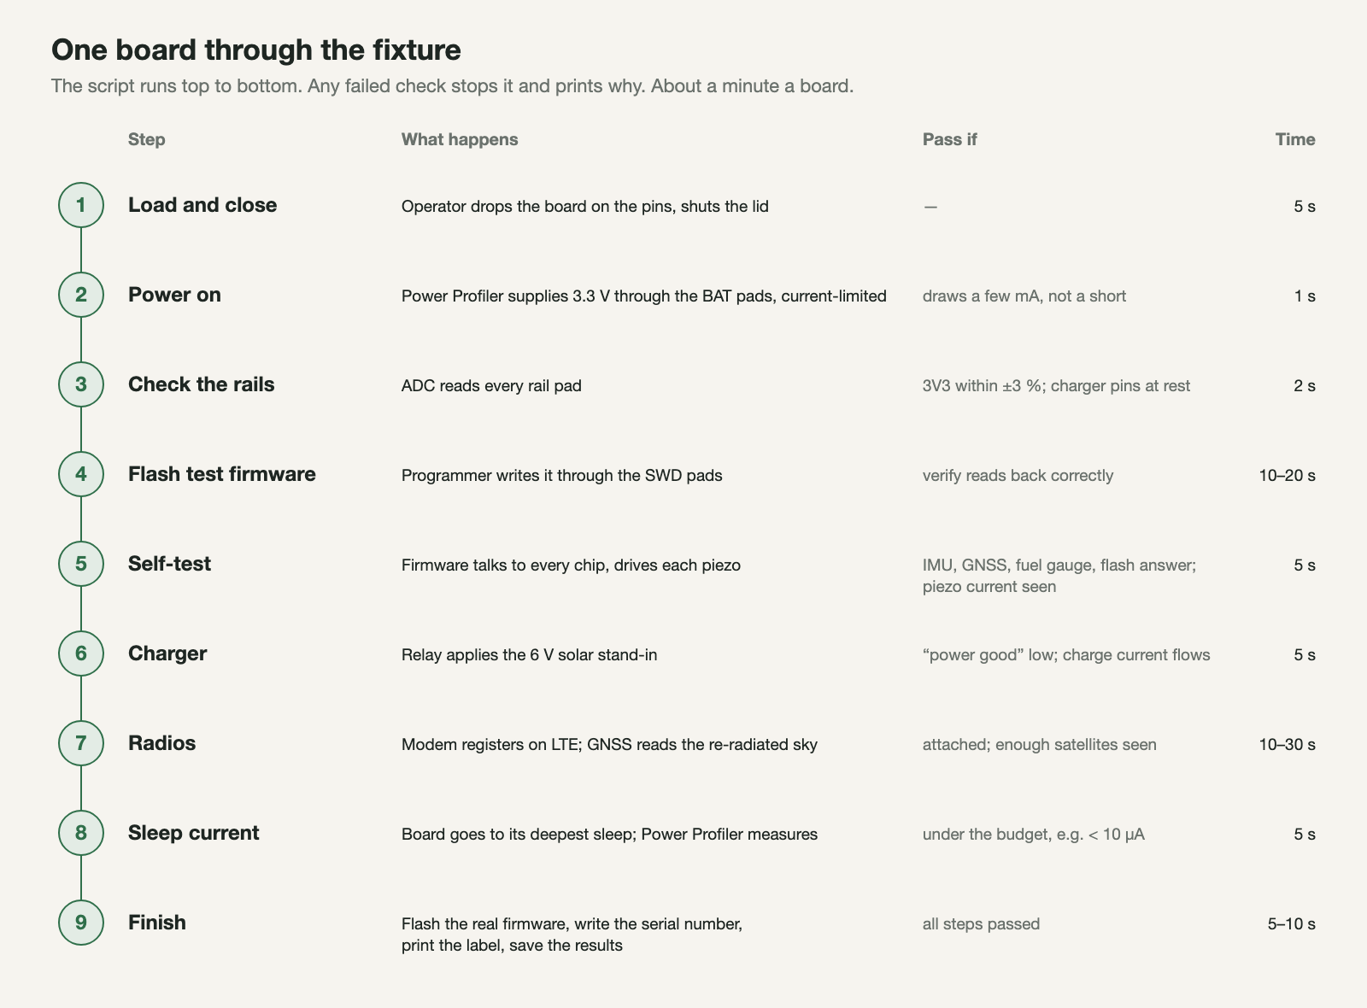
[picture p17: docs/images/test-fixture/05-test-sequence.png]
The test sequence


The script is plain Python. Each step has a pass/fail rule, and the first failure stops the test and says why ("3V3 rail is 2.1 V: expected 3.2–3.4 V"). Every result is saved against the board's serial number. When a collar comes back from a farm, we can look up exactly how that board tested on the day it was made.

The **sleep-current check** matters most for us. A board that "works" but draws 200 µA asleep instead of 5 µA flattens its battery in weeks, not the 60 days we promise. Nothing else would catch that before a farmer did.

## 6. Our carrier board today

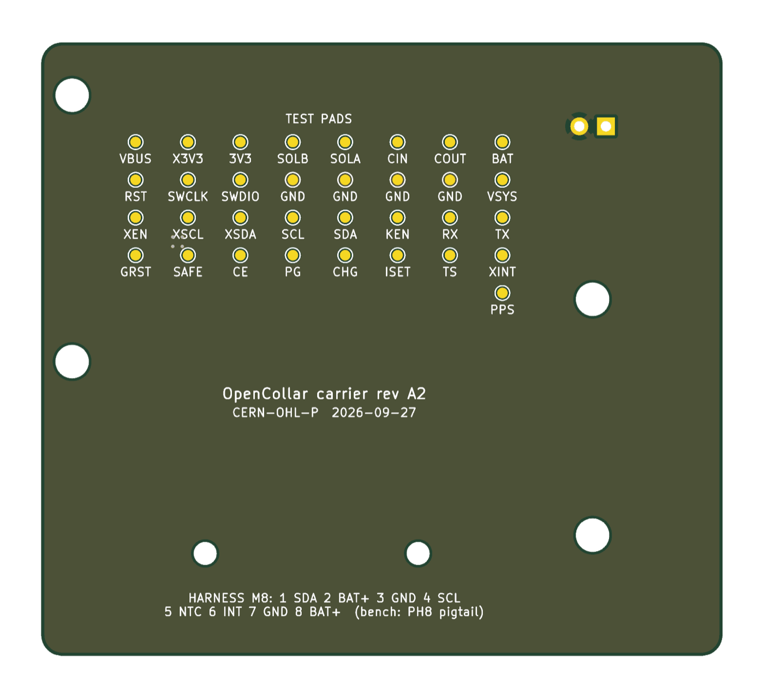
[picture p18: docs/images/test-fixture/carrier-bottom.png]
Our carrier board from below


*The real carrier board from underneath. The yellow dots are the 33 test pads; the white circles are holes.*

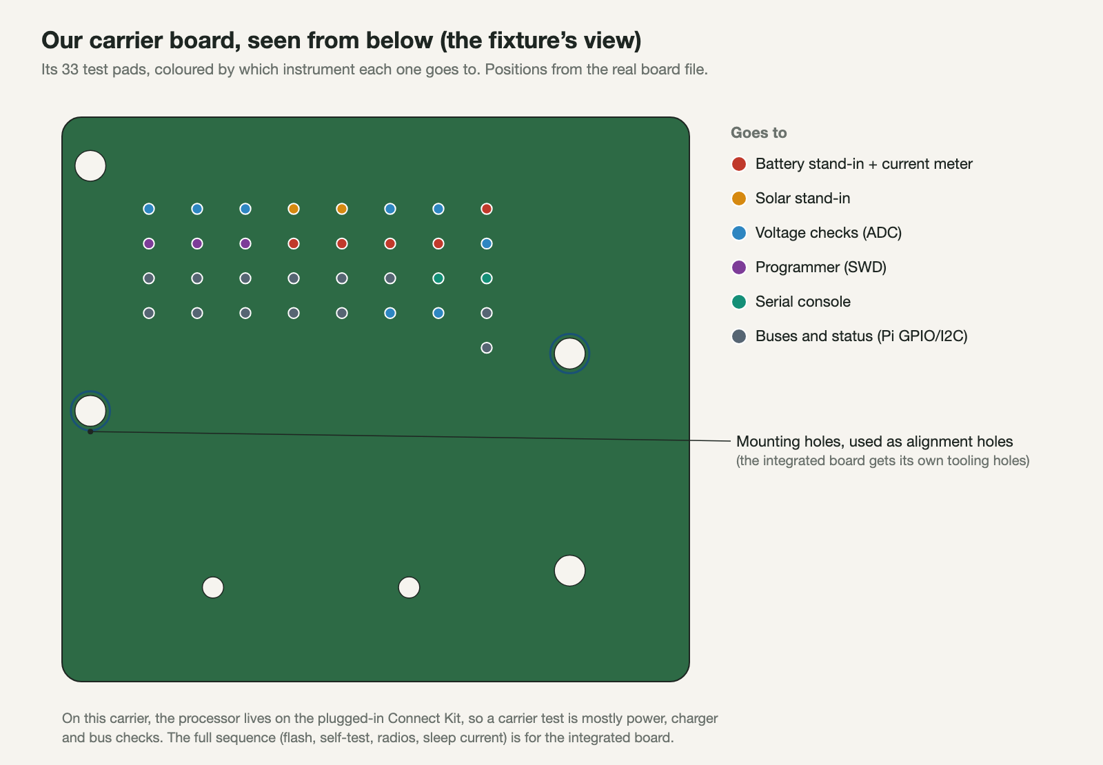
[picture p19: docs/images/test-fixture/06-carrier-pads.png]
The carrier's pads by instrument


The carrier was designed with test pads from the start (`hardware/carrier/SPEC.md` section 7). It's missing two things a production fixture wants:
- **Dedicated tooling holes.** The pictures use two of its mounting holes as stand-ins.
- **The brains:** the processor is on the plugged-in Connect Kit, not on the carrier. So a carrier test is mostly power, charger and bus checks.

For 5–10 alpha boards, a multimeter and a bench supply are enough anyway.

## 7. What the integrated board has to include

"Designing the test fixture alongside the board" means these go into the board's spec before layout starts:

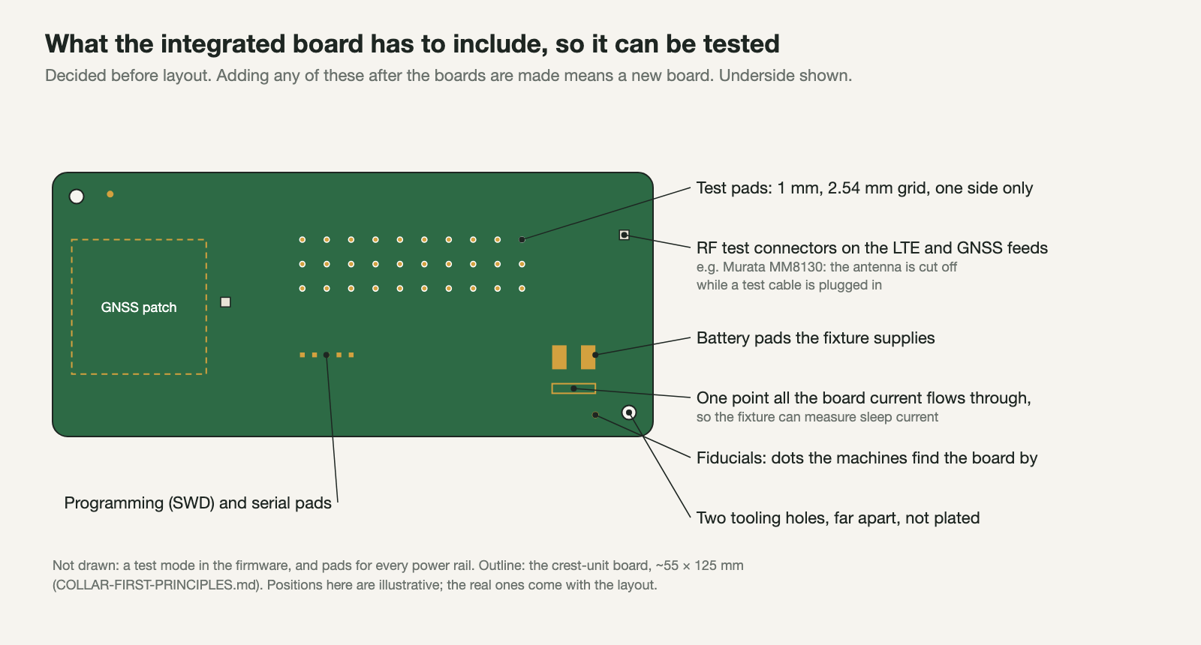
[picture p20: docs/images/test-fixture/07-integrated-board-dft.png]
What the integrated board needs


| Feature | Why | Example |
| --- | --- | --- |
| Test pads for every rail and signal the script checks | The pins need something to press on | 1 mm round pads on a 2.54 mm grid, all on the underside |
| Two tooling holes, far apart | Puts every board in exactly the same spot | 3 mm unplated holes in opposite corners |
| Fiducials | Lets the assembly machines and the fixture camera find the board | 1 mm copper dots |
| Battery pads plus one current path | So the fixture can power the board and measure sleep current | All board current flows through one point |
| Programming and serial pads | Flash firmware, read test output | SWD (clock, data, reset) and UART pads |
| RF test connectors | Check the LTE and GNSS radio paths with a cable instead of over the air | Murata MM8130 switch connector: plugging a test cable in disconnects the antenna |
| A test mode in the firmware | The board has to answer "test yourself" commands | A small command set on the serial port |

Miss one of these and you find out after the boards are made. At that point it's a new board, or testing by hand.

## 8. How we'd build our first fixture

1. **Export the pad map.** The positions come straight from the board file: `images/test-fixture/export_pads.py` writes them to `tp.json`.
2. **Order the probe plate as a circuit board from JLCPCB:** a blank board whose drill holes are the pad positions, sized for the receptacles. It costs a few dollars and is accurate to a fraction of a millimetre.
3. **Press in receptacles, drop in pogo pins,** and solder one wire from each to a terminal board.
4. **Print the frame and lid** on the Ender, with two steel dowels as alignment pins and a toggle clamp.
5. **Wire up the station** (section 4) and write the test script: one Python file, one function per step in section 5.
6. **Test the fixture with a known-good board,** then a deliberately broken one, to make sure it catches the fault.

## 9. Words you'll hear

| Word | Meaning |
| --- | --- |
| **DUT** | "Device under test": the board being tested |
| **Bed of nails** | A fixture with a plate of spring pins |
| **Pogo pin** | A spring-loaded probe pin |
| **Test pad / test point** | Bare copper on the board for a pin to touch |
| **Tooling hole** | A hole only for positioning the board |
| **Fiducial** | A copper dot machines use to find the board's position |
| **FCT** | Functional test: power it up and check it works (what this document describes) |
| **ICT** | In-circuit test: measures each part individually with many more pins. Common in big factories, overkill for us |
| **Flying probe** | A machine with moving probes instead of a fixture; slow but needs no fixture. Some assemblers offer it |
| **AOI** | Automated optical inspection: a camera checks the soldering. The assembler does this |
| **SWD** | Serial Wire Debug: the two-wire port used to program ARM chips like the nRF9151 |
| **UART** | A simple serial text connection, for the board's messages |
| **Sleep current** | What the board draws while idle; sets battery life |
| **Yield** | The share of boards that pass. 98 % yield means 2 in 100 need rework |

## 10. How these pictures were made

Everything here is regenerated from the real board:

```sh
cd hardware/carrier && source env.sh
uv run python schematic.py && kicad-python layout.py build/carrier.net build/carrier.kicad_pcb
kicad-cli pcb export glb --subst-models --include-tracks --include-pads --include-silkscreen \
    --include-soldermask --include-zones --output build/carrier.glb build/carrier.kicad_pcb
cd ../..
kicad-python docs/images/test-fixture/export_pads.py \
    hardware/carrier/build/carrier.kicad_pcb docs/images/test-fixture/tp.json
python3 docs/images/test-fixture/diagrams.py                 # the SVG diagrams
/Applications/Blender.app/Contents/MacOS/Blender --background --factory-startup \
    --python docs/images/test-fixture/render_fixture.py -- \
    hardware/carrier/build/carrier.glb docs/images/test-fixture/tp.json docs/images/test-fixture
```

The PNG diagrams are the SVGs screenshotted by headless Chrome; the renders were converted to JPEG with `sips`.

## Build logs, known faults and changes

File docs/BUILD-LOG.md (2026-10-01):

# Build log

## 2026-09-25

- All prototype parts delivered.
- Repo created. Next: lay out parts and photograph them for the BOM.
- Parts laid out and photographed (`hardware/photos/2026-09-25-parts-layout.jpg`). BOM recorded.
- The nRF9151 Connect Kit does MCU, cellular, and GPS on one board, so the only external module is the Qwiic buzzer (I2C). The kit also has an onboard LiPo charger.
- Gaps found: no SIM yet; no way to connect the buzzer with the jumpers on hand (needs a Qwiic-to-jumper cable or headers soldered on).
- Board powered over USB-C from the Mac. All LEDs green. Enumerates as `Makerdiary IFMCU CMSIS_DAP` with two serial ports:
  - `/dev/cu.usbmodem2101`: nRF9151 running Nordic Modem Shell (`mosh:~$`). Factory firmware.
  - `/dev/cu.usbmodem2103`: interface MCU shell (`ifsh:~$`) with charger, SIM detect, VIO, reset, and UF2 bootloader commands.
- Modem: nRF9151-LACA, modem firmware `mfw_nrf91x1_2.0.4`. System mode LTE-M + NB-IoT + GNSS.
- IFMCU firmware v2.0.0 (NCS 3.3.99, built 2026-06-19).
- VIO is 3.3V (buzzer needs 3.3V).
- SIM detect: uninserted, as expected.
- Charger (BQ25180): regulation 4200 mV, fast charge 100 mA, input limit 500 mA. Safe for the 1200 mAh LiPo (~0.08C). Battery still not connected; polarity not checked yet.
- GNSS LNA enable (`AT%XCOEX0`) already set for 1565–1586 MHz by factory firmware.
- First GNSS test, indoors on the desk, cold start, GNSS-only mode (`AT+CFUN=31`): no fix after ~170 s. Satellite 19 was tracked intermittently at C/N0 24–35 dB-Hz, so the antenna → LNA → receiver chain works. A fix needs 4+ satellites, which means a window or going outside.
- **First GPS fix.** Cold start, GNSS-only mode, no assistance data.
  - Garage with the door open: only 1–3 satellites usable. Not enough.
  - Antenna moved into open sky: fix about 3 minutes later (318 s since GNSS start). Accuracy 5.9 m at first fix, settling to **2.2 m** within about a minute. HDOP 1.6, 5–10 satellites in fix, strongest C/N0 42–44 dB-Hz.
  - Takeaway: the antenna needs a clear view of the sky, which it will have on a collar. Cold starts take minutes; A-GNSS over LTE will cut that to seconds once the SIM is in.
  - Exact coordinates deliberately not recorded here (home location, public repo).
- Firmware research done. Decision: write our own firmware on the nRF Connect SDK.
  - OpenFence (GPL-3.0, 2016): no code taken. Its geofence uses float lat/lon, clamps segments incorrectly, and has no warning zone or hysteresis. Ideas kept for later: volume rising with depth, directional cues, silence when the animal turns back, wake on motion, report-on-move.
  - Makerdiary board files (Apache-2.0) vendored into `firmware/boards/`. Build target `nrf9151_connectkit/nrf9151/ns`, flash with pyOCD over the onboard CMSIS-DAP.
  - Nordic Asset Tracker Template is the reference for the later modular structure (network, location, cloud, storage, FOTA over zbus).
  - Qwiic Buzzer register map taken from SparkFun's MIT-licensed library.
- **Battery connector:** the board's socket (J2) is **MX1.25-2P (1.25 mm pitch)**, not JST-PH 2.0. Check that the LiPo plug physically matches and that red goes to `+` on the silkscreen before connecting.
- Geofence engine (`firmware/src/geofence.c`) and cue policy (`firmware/src/cue.c`) written as plain C with host tests. All pass (`make -C firmware/tests/host`).
- nRF Connect SDK v3.4.1 installed via `nrfutil sdk-manager` (in `/opt/nordic/ncs`). Build with `nrfutil sdk-manager toolchain launch --ncs-version v3.4.1`.
- Factory nRF9151 flash backed up to `~/opencollar-backups/factory-nrf9151-flash.bin` (1 MB, via pyOCD) before flashing.
- **First flash of our firmware.** Attempt 1 crashed with a BusFault: the factory TF-M/bootloader was still at 0x0 and our image used the board's default MCUboot layout. Fixed by using Nordic's no-bootloader partition layout (same as Makerdiary's samples). Attempt 2 boots: TF-M 2.3.1 → NCS 3.4.1 → `OpenCollar V0 starting` → boundary v1 loaded → GNSS started → tracking satellites. Buzzer reports not found (not wired yet), as expected.
- Competitor GNSS research written up in `docs/research/virtual-fence-gnss.md`; V1 requirements and shopping list updated from it.
- Collar protocol drafted in `protocol/README.md`: boundaries down (one ring, 3–64 vertices, versions only go up), acks and position reports up. Fence logic stays on the collar. Transitions and exclusions are handled by the server, so V0 firmware only ever sees a single polygon. Transport (likely CoAP or MQTT over LTE-M, CBOR) not decided.
- Retrieved FCC internal photos with Firecrawl (auto proxy; fccid.io needed a click-through). **Halter P5 uses a u-blox M10 chip (UBX-M10050-KB) + SX1262 LoRa + STM32WBA65. Vence uses a u-blox ZOE-M8B with an ~18 mm patch. Nofence C2 uses a ~25 mm patch on a big ground plane + u-blox SARA-R412M cellular.** Nobody uses L5.
- Nofence field study (doi:10.1186/s40317-025-00417-1): real accuracy error 5.4 m open, 7.6 m forest. That's the bar to beat, not the ±1 m marketing claims.
- Wrote `docs/V1-DESIGN.md`: sealed top unit (MAX-M10S GNSS at the crown, solar either side, nRF9151, LiFePO4 inside), passive counterweight, no wires in the strap. Targets ≤ 2.5 m open / ≤ 4 m canopy, 60+ days without sun, ≤ 1.2 kg.
- Replaced the fixed counterweight with a **bottom bay** of swappable modules in a fixed mass window: ballast (default), camera (GoPro mount + power bank as the mass), battery later. No electrical connection through the strap; modules talk over BLE if needed. Pulse module goes inside the top unit so every collar can enforce. See `docs/BOTTOM-BAY.md`.
- Product lineup set: base collar = top unit + plain strap + ballast module. Add-ons: **Battery Extension** (LiFePO4 pack ~45 Wh + powered strap, extends no-sun autonomy from ~60 to ~190 days) and **Camera**. V1 top unit gets the sealed extension connector and power path now so the battery is a field upgrade.
- Changed to a **wired strap on every collar** (one strap, plug-in modules, collar power for the camera). Conditions: collar never depends on it, short-circuit protected port, wires only in the fixed-length strap section, flex-rated wire + IP68 connectors, and V1-alpha straps wired from day one to prove durability.
- Shopping list rewritten in five stages (bench + GPS, power, V1-alpha shells, camera, field). ~$1,800–2,400 total.
- Blender tooling plan in `docs/DESIGN-TOOLING.md`: blender-mcp for live sessions, headless scripts in `mechanical/` as the source of truth, and a six-step self-review checklist. Blender not yet installed.
- Cut to **one collar first**: the built-in GPS and a MAX-M10S log side by side on the same board, so extra kits aren't needed yet. Shopping list down to ~$900–1,200 including the camera.
- Volume cost estimate with pulse module added to `docs/V1-DESIGN.md`: BOM ~$85–115, all-in ~$110–160 per collar at 5,000 units (~$170–270 at 1,000).
- Materials and strap approach in `docs/MATERIALS-AND-STRAP.md`: buy a commercial cattle strap, print only the top unit, bay and modules. ASA (desktop FDM) or PA12 (MJF/SLS) for rigid parts, TPU 95A for clamps and bumpers, bought silicone O-rings. No PLA/PETG. Light colours.
- Wiring on a bought strap: a separate harness, an off-the-shelf high-flex M8 4-pin cordset (robot/drag-chain cable, IP67/68) between panel sockets on the top unit and bay, clipped along the fixed side. 5 V bus either end can supply (BQ25798 dual input + OTG), I2C for module ID/fuel gauge/camera control. Camera module is now Battery + Camera (pack with GoPro mount) so it never drains the fence battery; prototype uses a pass-through power bank.
- Two versions agreed: **DIY** (bought strap + printed parts, unwired; ballast or standalone GoPro+power bank; optional M8 harness) and **sold OpenCollar** (wired strap; supports Battery Extension and Battery + Camera). Same top unit, firmware and bay standard.
- Prototype cart verified and saved to `hardware/prototype-cart.md` (~$916 incl. camera and PPK2).
- Filled guest carts in the T3 browser: Amazon, SparkFun, Adafruit, Pololu, Voltaic, United Lithium, K&J, Heritage (strap; Coburn is dealer-only). DigiKey and TI block automated adds; GoPro and Hologram left to do by hand. Status and DigiKey paste list in `hardware/prototype-cart.md`.
- Parts revenue options in `docs/PARTS-REVENUE.md`: affiliate links earn ~$10–20 per build (SparkFun 10% on Originals, Amazon ~3%, GoPro 3%, Adafruit none); kits ~$100–200 margin each. Recommend both: disclosed affiliate list now, kits after the prototype works.
- Strategy set (`docs/STRATEGY.md`): assembled OpenCollars first; proprietary collar later; open device API always; paid OpenPasture subscription. Permissive licences (Apache-2.0 / CERN-OHL-P / CC BY) so the proprietary collar can reuse open work.
- DIY power path changed to need no software: Adafruit bq24074 solar charger (4.2 V fixed) + protected 6600 mAh Li-ion pack + thermistor. Shipped collars keep LiFePO4 + BQ25798 with charging held off in hardware until configured. Shop build page updated (DIY parts ~$305 without PPK2).
- **Simplified the first build** to what it must prove (GPS, fence/cue, telemetry, physical collar): 6 checkouts instead of 11, ~$260. Switched our prototype to the no-config Li-ion power path (bq24074 + 6600 mAh pack + thermistor); IMU now Adafruit ISM330DHCX; Adafruit 960 reference antenna. Deferred: TI board + LiFePO4, PPK2, camera module, harness, piezo, hall sensor, SPI flash, fuel gauge. Removed cut items from the Amazon cart; DigiKey rows pre-selected for deletion (click Delete). Shop DIY page updated to match.

## 2026-09-26

- **Collar rule: only cue a crossing.** The collar now cues "outside" only when the animal goes from inside (or the warning zone) to outside under the boundary it holds. At boot and after every new boundary the fence is unarmed; the first fix inside the polygon arms it. Unarmed and outside means silent, state `outside`. After a crossing (10 s of outside tone) it disarms, so an animal walking back in isn't cued in the warning zone on the way. 10 s outside limit and 20 s active / 30 s rest unchanged.
  - Why: an audio cue only teaches when the animal can escape it by moving away from the edge. A fence drawn on top of an animal gives no direction, only noise, and cueing an animal that is already out punishes it for coming back.
  - Enables moves as sweeps: openpasture sets a target and sends a series of boundaries whose back edge sits just behind the rearmost animal, so only those animals hear the warning cue and walk forward. The collar needs nothing new for it; each step is a newer boundary.
  - `cue_rearm()` added to `cue.c`; `main.c` applies every boundary through `apply_boundary()`, which calls it. Boundary download over LTE should use the same function.
  - Host tests added: a new boundary that leaves the animal outside gives no cue, walking in arms it, crossing out cues; a new boundary with the animal in its warning zone cues at once. All pass (`make -C firmware/tests/host`). Firmware still builds (NCS v3.4.1, 68.8 KB flash).
  - `protocol/README.md` updated with the rule, `herd_id` in the boundary command (signed by the server; a collar rejects another herd's boundary), and a note on moves. The same rule is ported to openpasture's `op-geo` and its collar simulator.

## 2026-09-26

- **3D design setup.** Blender 5.2.2 installed. MCP for Blender add-on installed and enabled, telemetry off, and registered with Claude Code as the `blender` MCP server (user scope). Live socket test from Python works. 3D Print Toolbox extension installed.
- `mechanical/` pipeline built: `./build.sh` runs each `parts/*.py` in headless Blender and exports STL. It renders front/side/top/bottom/iso views plus a section with cut faces in red, and checks manifold, normals, minimum wall (inward ray cast), size against spec and clearance against reference bodies. Volume and solid mass are reported. Any failure gives a non-zero exit.
- The wall check caught knife-edge slivers inside engraved digits (6, 9, 3 in Blender's font). Labels get an explicit, commented allowance; structure is still checked at 1.2 mm.
- Reference dimensions researched into `mechanical/lib/dims.py` from vendor drawings and board files: nRF9151 kit 55.88 × 20.32, MAX-M10S 38.1 × 30.48, bq24074 38.1 × 33.02, 6600 mAh pack 69 × 54 × 18 / 155 g, P124 panel 113 × 66 × ~3, vent M6 × 0.75 (wall ≥ 4, chamfer to Ø8.6), 2 mm cord groove 2.9 × 1.5 (ERIKS). The strap is **44.45 mm (1-3/4")**, not the 50 mm in the V1 docs. Thickness, several board heights and antenna sizes aren't published; to measure.
- First printable parts for the fabrication partner: `fit_test` (sweeps insert, M3 clearance, O-ring groove and vent tap-drill sizes) and `seal_box` (76 mm box and lid with the top unit's seal: O-ring face groove, 4 M3 inserts, M6 vent; for a 1 m / 30 min submersion test). Both pass all checks.
- Note for the top unit: two P124 panels (113 × 66 each) either side of the GNSS patch make the top unit much wider than the 130 × 90 mm in `MATERIALS-AND-STRAP.md`. Panel choice vs. footprint to decide when the top unit is drawn.
- **Collar V1-alpha, draft 1, designed in Blender** (`mechanical/lib/collar.py`, all checks pass):
  - Top unit 170 × 126 × 55 mm. Base with 13 mm solid walls carrying the O-ring face groove; roof lid with the GNSS patch under a flat crown and a P124 panel recessed into each 18.7° face. The underside is an R300 arch with flat feet at the ends and a strap channel across it; two clamp bars with M3 button-heads grip the strap on the feet.
  - The lid is held by 10 × M3 × 16 screws **from underneath**, so the panels never cover a screw.
  - Inside: the 6600 mAh pack low and central (mass low, on the centreline); Connect Kit, IMU and buzzer on the right; charger and MAX-M10S on the left, all on printed standoffs; 70 × 70 ground plane under the patch; LTE flex on the far end wall; M6 vent in the end wall below the seal.
  - Bay: 104 × 66 cradle with a strap tunnel, plus a ballast module (70 × 46 × 16 steel, ~404 g) on 2 × M3 thumbscrews.
  - Estimated collar ~1.1–1.2 kg: top ~500 g, bay ~540 g, strap ~100 g.
- Assembly (`mechanical/assembly/collar.py`) puts it on a strap around a 25 × 42 cm neck section, saves `collar_v1_alpha.blend` and renders front, side, top unit, exploded, inside, underside and bay views. Loaded into the live Blender session over the MCP add-on's socket.
- `mechanical/package.sh` zips STLs, renders, the .blend and `PRINT-LIST.md` for the fabrication partner: `output/opencollar-v1-alpha-2026-09-26.zip` (20 MB).
- Design issues the checks caught and fixed on the way: the arch feathering to a knife edge at the ends (now steps onto flat feet), clamp bar counterbores breaking out of the bar ends, the insert holes under the panel recesses leaving 0.2 mm, board posts poking into the strap channel, the battery sitting in the thicker floor over the strap, and overlapping battery locators making the mesh non-manifold.
- **Scale and dimension check** of the collar design:
  - Units: the Blender scene is metric, mm, scale 0.001, so 1 unit = 1 mm. Every exported STL was measured from its triangles and matches its design size to 0.01 mm: base 170 × 126 × 24, lid 170 × 126 × 31, bar 12 × 70 × 5, cradle 104 × 66 × 16, module 104 × 66 × 22.
  - Bought parts against vendor sources: the MAX-M10S, bq24074, ISM330 and Qwiic Buzzer outlines and mounting holes match their Eagle board files exactly. The nRF9151 kit (55.88 × 20.32, Ø1.4 holes 1.27 in, 17.80 c-c) matches Makerdiary's dimension drawing. The P124 panel (113 × 66 × 2.8 ± 0.3) and the vent (M6 × 0.75, 7.0 thread, 10 AF / 10.6 AC hex, 12.3 long) match their drawings.
  - Fixed: the panel wire hole was a single Ø5 hole but the P124 has **two 4 × 4 pads at 6 mm pitch**. Now a 14 × 9 slot 17 mm from the +Y edge, centred across the panel so it reaches the pads with either long edge up.
  - Fixed: the clamp-bar screws were M3 × 10 and would have bottomed out in the 6 mm insert hole; now **M3 × 8** (5 mm engaged).
  - Fixed: the thumbscrews only reached 2 mm into the 4 mm insert. The head recess is now 6 deep (4 mm engaged with M3 × 20); screws moved to x ±40 and the steel slab shortened to **64 × 46 × 16 (~370 g)** to clear it. Bay ~505 g, still inside the 450–650 g window.
  - Checked OK: lid screws M3 × 16 (11 mm clamp + 5 into a 6 mm hole); seal box M3 × 8 (2.8 + 5.2 into 6); O-ring groove 2.9 × 1.5 for 2 mm cord (25 % squeeze, 72 % fill).
  - Flagged: the strap loop around the modelled 107 cm neck is 1,156 mm of the 1,219 mm strap, so little is left for the buckle. Measure the pilot animals' necks.
- **PLA quick-look print on the Ender-3 V3 SE** (checks size, fit and layout, not strength). OrcaSlicer 2.4.2 installed. `mechanical/print/` has `orient.py` (writes print-oriented STLs), `flatten_profiles.py` (turns OrcaSlicer's bundled V3 SE / Generic PLA presets into standalone CLI presets with our overrides) and `slice.sh`.
  - Quick-look profile: 0.28 mm layers, 2 walls, 0 % infill, grid supports. Tree supports doubled the time: the underside arch and the inside of the roof both need support.
  - Plates: `OC1_top_base` (base + 2 clamp bars) 4 h 45 m, 114 g; `OC2_top_lid` 3 h 49 m, 108 g; `OC3_bay` (cradle on its side + module) 2 h 10 m, 61 g. About 10.7 h and 283 g PLA in total. All toolpaths sit inside the 220 × 220 bed.
  - With the production-like 0.24 mm / 10 % infill / tree supports settings it was about 24 h and 350 g.

### Carts reset to the prototype list (2026-09-26)
- DigiKey: started a new cart with only the MAX-M10S breakout and the M6 vent ($49.26). The old cart had parts deferred to build two.
- Amazon: only the 5 collar items are selected for checkout ($61.35). Other items in the cart are unticked, not deleted.
- Voltaic: re-added 2 × P124 panels ($28.00). Heritage: strap ($23.10).
- Emptied SparkFun, Pololu, United Lithium and K&J.
- Adafruit: automated adds were silently dropped until Cody created an account and signed in; then all 9 items went in ($98.60).

### Prototype parts ordered (2026-09-26)
Cody placed all six orders: DigiKey, Amazon, Adafruit, Voltaic, Heritage, Hologram. Total $260.31 plus shipping and tax (list in `hardware/prototype-cart.md`).
When the boxes arrive: photograph the parts, check every item against the list, then bench-test power (panels → bq24074 → pack → nRF9151) before anything goes in a shell.

### Board design toolchain installed (2026-09-26)
- KiCad 10.0.6 in `/Applications/KiCad`; `kicad-cli` and a `kicad-python` wrapper (KiCad's bundled Python with `pcbnew`) in `~/.local/bin`.
- Chose **SKiDL** (MIT) for schematic-as-code. Tried atopile first: its command-line tool is in maintenance mode and moving to a hosted app that needs an account, so it was uninstalled.
- `hardware/carrier/` project: a smoke test goes SKiDL → netlist → `.kicad_pcb` → DRC → render, all headless. Works.
- Method written up in `docs/DESIGN-PHASE.md`. Next: the carrier board spec.

### Carrier board spec drafted (2026-09-26)
- `hardware/carrier/SPEC.md` written; waiting on Cody's sign-off before the schematic.
- **Connect Kit pinout** taken from Makerdiary's rev A hardware diagrams and dimension drawing: 2 × 20 pins, 2.54 mm pitch, rows 17.78 mm apart, pin 1 (VBUS) and pin 40 (VIO) 3.81 mm from the USB end. The header has **no battery pin**. The battery reaches the Kit only through J2 (MX1.25) or test pad TP3, so the carrier feeds J2 through a 1.25 mm pigtail. VSYS (pin 2) is an output. The parts photo shows the Kit came with male pins fitted.
- **Charger from TI's BQ2407x datasheet (SLUS810N).** Key finding: VIN-DPM, which stops the charger from collapsing a solar panel, only works in the USB modes (EN2 low). The charger runs in USB500 mode: 500 mA input limit, ISET 887 Ω (1 A programmed, so it's input-limited and the safety timers slow down), TMR 72 kΩ, ILIM 3.24 kΩ fitted (charging is disabled without it), TS straight to the 10K NTC (about 3–47 °C with B3950; no NTC means no charging, fail-safe), CE pulled low, EN1 tied to OUT so it works without the Kit.
- The Kit is powered from bq24074 OUT (4.3–4.5 V, inside J2's 3.6–4.65 V). 3.3 V for every breakout comes from the Kit's VIO (TPS63901, over 400 mA).
- Panels: Voc 7.28 V (P124 datasheet), so the charger input can reach ~8 V when cold. That rules out the 5.5 V ideal-diode chips there. Each panel gets a Schottky; the harness 5 V goes through an LM66100 (off unless firmware enables it) and then a Schottky.
- **Harness port:** 5 V, GND, SDA, SCL in M8 sensor order (1 brown +5 V, 2 white SCL, 3 blue GND, 4 black SDA). 5 V is input-only on this board. I2C goes through a TCA4307 hot-swap buffer (7 V-tolerant pins, stuck-bus recovery, off by default).
- **Buzzer:** keep the Qwiic Buzzer on a 4-pin socket. The MAX-M10S and ISM330 plug into female sockets, not Qwiic, so EXTINT, RESET, PPS, UART and the IMU interrupts reach the nRF. Pin maps read from the SparkFun/Adafruit board files, mating interface only. The ISM330's order comes from its sister LSM6DSOX board: check the silkscreen.
- **Board shape from the shell model:** a 143 × 99 mm ring around a 61 × 75 mm cutout for the pack, board underside at z = 18. The floor is only 0.7 mm below the inner edge, so the bottom side carries only test pads. Lid headroom falls from 52 mm at the crown to 33.9 mm at x = 70, which keeps the MAX-M10S inboard of x = −62. The vent bore needs a notch in the board edge.
- MAX-M10S draws 9.5 + 2.3 mA in continuous tracking (u-blox Table 15). Its TIMEPULSE shares a pin with SAFEBOOT_N, so it must never be pulled low at boot.
- Power budget: ~300 mAh/day known (GNSS dominates) plus unmeasured idle currents (Kit overhead, buzzer, IMU board): ~19 days without sun. Estimated harvest ~700 mAh/day in winter, ~1,400 in summer. The 60-day target needs GNSS power-save or duty-cycling in firmware.
- LCSC checked: BQ24074RGTR C54313, LM66100DCKR C2869734, TCA4307DGKR C880333 (extended parts).
- Open: ring vs. two boards; harness 5 V input-only for alpha; bench checks when parts arrive (pinouts, pull-up and LED jumpers, idle currents, buzzer dB through the shell, heights, pack lead). List in SPEC.md section 11.

### Collar redesign from first principles (2026-09-26)
- Cody wants the collar slim and sleek, as close to Halter's as we can get, designed from first principles rather than around the dev boards. Written up in `docs/COLLAR-FIRST-PRINCIPLES.md`; competitor findings with sources in `docs/research/collar-form-factors.md`.
- Halter, from a 2026 peer-reviewed trial: 488 g on the neck plus a 912 g counterweight, 1.40 kg. The top unit is two side pods joined by a flexible bridge (US design patent USD1089882S), and the counterweight is almost certainly dead mass that also sets the collar size. Nofence C2.5 is a 15.3 × 14.5 × 5.4 cm box at ~1.5 kg with a 72 Wh battery. Monil is a top puck plus a weighted lock, ~1 kg. The P5 FCC exhibits couldn't be reached.
- **Draft 1 fails the stability rule.** Bottom : top is ~1 : 1 (500 g over 505 g) against Halter's 1.87 : 1. Its 170 × 126 × 55 mm size comes from dev boards on standoffs and the 18 mm pack, not from anything the collar needs.
- Derived: only the GNSS patch, panels, LTE antenna, main board (as the patch's ground plane) and piezo need to be on top: ~195–225 g *est*. Every top gram needs ~1.8 g underneath.
- Two layouts compared at the 60-day / ~20 Wh target. **A (Halter's):** battery on top, ~26 mm thick, ~1.18 kg collar. **B:** the battery is the counterweight, with a small buffer cell on top, ~16–18 mm thick, ~0.78 kg collar. Recommended B, gated on the V1-alpha harness durability test. With a cut strap wire, B keeps the fence running on the top's own panels and buffer, and loses only the no-sun reserve.
- Shape: one low puck on the neck crest, ≤ 120 × 80 × 18 mm, ≤ 250 g; the panel bonded in as the lid; the patch beside the panel, not under it; sizing at the bottom module like Halter. Our own look: Halter's shape is design-patented.
- Knock-on: draft 1 becomes the alpha test box; the carrier board becomes a plain rectangle under 100 × 100 mm (spec marked on hold for its outline); the integrated board gets shaped to the puck.
- Open for Cody: layout A or B, keep the 60-day target, carrier as a rectangle, puck vs side pods. Measurements needed: neck circumference and crest curvature on the pilot animals. Next: a cheap rotation test with 225 g on top and 420 g below, on a person first, then a steer.

### Repo published, collar contract moved in (2026-09-26)
- Published at https://github.com/open-pasture/opencollar. This backs up the local history and fixes the 404 behind the "The opencollar repo" button on openpasture.dev/collar/build.
- Checked before pushing: gitleaks 8.30.1 over all 43 commits found nothing, and a manual search for keys, tokens, SIM and Wi-Fi credentials and `.env` files found nothing either. The largest file is the 3.4 MB parts photo (its GPS tags are empty), well under GitHub's limits.
- The partner names already taken out of the docs were also taken out of the older commits, plus one leftover in `docs/BOTTOM-BAY.md`. Messages and dates are unchanged, but commit hashes differ from the old local history. The pre-publish history is kept as a bundle in `output/backups/`.
- The collar server contract, `docs/contracts.md` from the retired agent kit (commit c306c5c), is now `protocol/contracts.md`. `protocol/README.md` points at it and at the Rust app's `crates/op-protocol` and the Device endpoints section of its `docs/API.md`.
- Still missing: licence files. `docs/STRATEGY.md` plans Apache-2.0 for firmware, CERN-OHL-P for hardware and CAD, and CC BY 4.0 for docs. Until those files are added, the repo is all rights reserved by default.

### First-principles decisions and carrier rev A2 (2026-09-26)
- **Cody decided:** the battery is the counterweight (layout B); keep the 60-day no-sun target; the carrier is a plain rectangle; left and right sound cues, as Halter does; design to average neck sizes with adjustment instead of measuring the pilot animals.
- **Why two cues need two places:** cattle's minimum audible angle is ~30° (Heffner & Heffner 1992), so two speakers close together on top of the neck sound the same to the animal. One per side of the neck works. The top becomes a **crest unit** (GNSS, board, panel, buffer cell; ~60 × 130 × 18 mm) plus **two small ear pods** on the strap (a piezo each, pulse electrodes later), ~270 g *est*. Bottom ~505 g, collar ~0.9 kg *est*.
- **Neck:** fit range 75–130 cm (Monil's published range; indigenous Ethiopian cattle average ~70 cm). Design centre ~107 cm on an ellipse ~25 × 42 cm: crest radius ~74 mm, sides ~350 mm. The crest is tight and the sides nearly flat, which is why rigid parts go on the sides and only a narrow unit across the top. Estimates, not measurements.
- **Caught:** adjusting one side only puts the bottom off-centre, and the weight then rotates the top off the crest. Adjust both ends at the bottom module (Halter: "within one hole of each other") and store the harness slack there.
- **Caught:** with the pack under the throat, the charger's thermistor has to come up the harness. The bus changes from M8 4-pin 5 V to **M8 8-pin**: BAT+ ×2, GND ×2, SDA, SCL, NTC, INT (DIN 47100 colours). `BOTTOM-BAY.md` marked superseded.
- **Carrier rev A2** (`hardware/carrier/SPEC.md`): 95 × 75 mm with four M3 holes. The battery and NTC arrive over the harness (J_BAT and J_NTC kept for the bench). The LM66100 5 V input is gone. Two Qwiic cue ports feed the ear-pod buzzers (addresses 0x34 and 0x5B, set in software). Everything leaving the box sits behind a TCA4307 buffer plus a TPS2553 current-limited switch (LCSC C55266) on one EXT_EN line, so a chewed cable can't hang the GNSS/IMU bus and the buzzers draw nothing between cues.
- Alpha test box: board plane raised to z = 20 (a centred board sits over the strap channel), M8 socket, two ear pods, and a bottom module with the pack, a fuse, NTC and ~390 g of steel for ≥ 1.87 : 1.
- To buy when Cody's ready (not ordered): a second Qwiic Buzzer, two long Qwiic cables, an M8 8-pin cordset plus two panel sockets, JST-PH pigtails.

### Carrier schematic and first placement (2026-09-26)
- `hardware/carrier/schematic.py` (SKiDL): one function per block, each citing its datasheet section. Blocks: Connect Kit sockets, Kit battery feed, bq24074 charger, solar inputs, bench battery, ADC sensing, main I2C, GNSS sockets, IMU socket, external bus (TCA4307 + TPS2553), cue ports, harness, ESD, expansion, test pads, holes. The TCA4307 and TPS2553 have no KiCad symbols, so they're defined in the script from their datasheet pin tables.
- **ERC clean.** Netlist checked by hand: 96 parts, 53 nets, no single-pin or duplicated nets. Kit pins land on the right sockets (e.g. PPS on Kit pin 32 = P0.24, both Kit grounds).
- **Parts from JLCPCB's parts search.** Everything is stocked except a 1 × 20 SMD socket (3 pieces of one Samtec part), so each Kit row is two 1 × 10 hanxia 8.5 mm SMD sockets end to end. The bq24074 has only 816 in stock. 887 Ω, 3.24 kΩ and 71.5 kΩ have no Basic part. Full table in SPEC.md section 10.
- Changes on the way:
  - Both panels share one 3-pin PH (the right edge couldn't fit three 2-pin connectors).
  - The MAX-M10S's two holes beside its 8-pin row sit under the SMD socket, so it gets standoffs only on the far corners.
  - The IMU gets M2 standoffs to clear the GNSS socket.
  - The bq24074's thermal-via footprint uses 0.2 mm drills, so it gets four 0.3 mm vias instead (JLCPCB's standard minimum).
- `hardware/carrier/layout.py` (KiCad Python): places the fixed parts at computed positions (Kit rows 17.78 mm apart; breakout sockets at their board-file positions) and packs passives near their block without overlaps. Test pads go on the bottom with ≤ 5-character labels; GND pours on both layers; design rules set for JLCPCB (0.15 mm clearance and track, 0.3/0.6 mm vias).
- **DRC:** the only violations left are the intended end-to-end Kit sockets (2 courtyard overlaps and their silkscreen), plus 142 unconnected items because nothing is routed yet.
- **Caught in my own render review:** the LCSC/MPN fields were printing on the silkscreen over every part (now hidden). The Kit-battery "+ −" label sat over the wrong holes, so the polarity marks are now placed from the real pad positions. The board title covered U5's reference.
- Open before ordering: route (Freerouting still to install, it needs Java). Check the hanxia sockets' pad stagger against KiCad's Pin1Left and that the body is 25.4 mm long. Confirm the bq24074 RGT0016B land pattern.

## 2026-09-27

### Firmware 0.2: protocol v1 (branch `fr/ef`)
- **Scope:** the collar side of protocol v1 as rewritten in `protocol/README.md`: holes (up to 16, 384 vertices), shape rules, signed boundary and config commands, staged boundaries in flash, provisioning from the collar's card over the USB serial port. Boundary download over LTE waits for the SIM; the same code path takes a signed command pasted on the console.
- **Baseline first:** the unchanged firmware builds at 68 800 B flash, 20 640 B RAM. Run as `nrfutil sdk-manager toolchain launch --ncs-version v3.4.1 -- ./build.sh`, west can't find the SDK outside its workspace ("unknown command build"), so `build.sh` now sets `ZEPHYR_BASE=/opt/nordic/ncs/v3.4.1/zephyr` when it is unset and that directory exists.
- **Modules** (`firmware/src/`), all plain C except `main.c`, `console.c` and `store_nvs.c`, so they run in host tests:
  - `shape.c`: the twelve rejection codes in openpasture's order. Crossings and containment exact on e7 integers (int64 products compared, never subtracted); areas and gaps in single precision about the outer ring's first vertex, in the same order of operations as `op_geo::shape`. Built with `-ffp-contract=off`; the ARM build has no fused multiply-add instructions in the app (checked with objdump).
  - `geofence.c`: outer ring plus holes, distance to the nearest edge of any ring and which ring, box shortcut for far holes. The V0 API and tests are unchanged.
  - `cue.c`: cue kinds (`warn`, `outside`), track mode (fence runs, nothing sounds), episodes (`turned_back`, `crossed`, `rest`, `boundary_changed`).
  - `command.c`: records up to 16 top-level spans, sorts them, streams the canonical bytes into SHA-512 and checks Ed25519 with Monocypher 4.0.2 (`third_party/monocypher/`, CC0 or BSD-2-Clause, SHA-512 of the release tarball matches the published one). Coordinates go to e7 integers exactly from the decimal text.
  - `config.c`: signed config (herd, cadence, fast mode until a GNSS time, endpoint trial with a 24 h fallback), NVS id 3.
  - `slots.c` + `store.h`/`store_nvs.c`: 16 slots and 24 576 slot bytes on NVS (ids 0x100 + i), 192-byte header + 8 B per vertex with a CRC-32. A new record is always written before the ones it replaces are deleted, and boot tidies up after a cut. `acks.c`: acks waiting to go up, NVS id 2.
  - `provision.c`: `provision <card payload>` checks each field and stores the payload in NVS id 1; slots, config and pending acks are wiped first.
  - `app.c`: everything wired together. GNSS UTC from fixes is the only clock for activation, carried forward on the uptime counter between fixes. No boundary means no fence and no cues; the compiled-in example boundary is gone. A bench boundary loads as version 0 only with `CONFIG_OPENCOLLAR_BENCH_BOUNDARY=y` (default n) and `src/boundary_local.h`.
  - `main.c`: boot from flash, fixes and console lines on the main thread (`k_poll`), so Ed25519 runs on the 8 KB main stack.
- **Console commands** (115 200 baud): `provision <payload>`, `status`, `boundary <command>`, `config <command>`. No echo, so a pasted 12 KB command isn't slowed down.
- **Logging is now deferred** (was immediate): immediate mode holds interrupts off while each line prints, which would drop bytes of a long command arriving on the same port.

### Vectors and host tests
- The five vector files are copied byte-identical from openpasture tag `fr-w0` (`crates/op-protocol/tests/vectors/`, read from the integration worktree) into `firmware/tests/host/vectors/`. SHA-256 prefixes: commands `70aae176bce665a7`, config `51a6789c9a74e28d`, geofence `3bd4cb46e1bc260d`, shapes `6f0fbadbe45a7e29`, slots `4d2018eb54d91794`.
- `make -C firmware/tests/host` builds one binary per module (`-Wall -Wextra -Werror`) and all pass:
  - geofence: the V0 tests unchanged; margins around and inside holes, concave hole, nearest ring; `geofence.json` 20 cases within 1 mm; 384 vertices in 9 rings: ~500 ns per fix on the Mac.
  - shape: `shapes.json` 46 cases, every code covered; exact decimal to e7 (`1e-7`, halves away from zero, 180.00000001 out of range).
  - command: `commands.json` 36 cases, canonical bytes identical for every valid case; UTF-8, escapes, surrogates.
  - config: `config.json` 17 cases; fast mode ends at `fast_until` by GNSS time; endpoint kept after a successful report, back to the previous one after 24 h of failures, the trial surviving a reboot.
  - slots: `slots.json` 12 cases through the real flash path (every step followed by a reload from the store that must give the same state; `boot` steps reload for real); record round trip; every flipped byte of a 3 264-byte record is caught.
  - store: a power cut after every byte of an immediate insert (3 279 bytes written), a staged insert (298) and a tick applying a staged boundary (266) always leaves the old state or the new one; bad CRC, unknown format and wrong size are ignored; an empty store gives no fence and no cues.
  - cue: the V0 tests unchanged; kinds, each episode outcome, track mode silent, walking into a hole is a crossing, a hole drawn on an animal stays silent until it is clear.
  - provision: a valid payload is stored and wipes the slots; each bad field gives its `error <code>`.
  - app: end to end, including a staged boundary applied by the first fix after a reboot and a collar-scoped track-mode boundary with holes.
- Changing one expected result in each vector file (a scratch copy) makes the matching test fail, so the tests do compare against the files.

### Build
- `nrfutil sdk-manager toolchain launch --ncs-version v3.4.1 -- ./build.sh`, clean build, no compiler warnings.
- **Application image 115 300 B (112.6 KB)**, limit 440 KB. **RAM 73 776 B (72.0 KB) of 211 608 B**, 134.6 KB free. The new RAM: both fences 13.6 KB, e7 scratch 3 KB, slot headers 3.7 KB, receive/line buffer 12.3 KB, record buffer 3.3 KB, pending acks 2.7 KB, config and provisioning 2.8 KB, main stack 4 → 8 KB, deferred log buffer and thread 6 KB.
- Worst stack on the main thread (GCC `-fstack-usage`, `-Os`): about 2.5 KB for a signature check (`crypto_eddsa_check_equation` 1 088 B), about 1.5 KB for shape checks and applying a boundary.
- Partition map, printed by `scripts/check_image.py` after every build, every edge on a 32 KB SPU boundary:
  - `0x00000-0x08000` TF-M (32 KB)
  - `0x08000-0xF0000` application (928 KB)
  - `0xF0000-0x100000` storage (64 KB, was 32 KB at 0xF8000)
- `CONFIG_NVS_INIT_BAD_MEMORY_REGION=y`: the new storage area was part of the application area, so NVS formats it if it finds old bytes there.
- Not flashed in this step (the board may be in use). On the next flash: paste a card payload, check `status`, and check the boot log says "No boundary: no cues".
- Open: LTE wiring (report, ack and boundary download over HTTP) once the SIM is in; the position report serializer; the console keeps the UART receiver on, which costs power on battery (the production board should enable it only with USB present).

### Herd change drops the old herd's staged boundaries (branch `fr/fx-fw`)
- **Problem (field-ready review):** a signed config naming another herd only changed the herd that new boundaries were checked against. Staged boundaries already accepted for the old herd stayed in the slots and on flash, and `slots_tick` applied them when due, with no herd check, as did boot. A collar moved from herd A to herd B, holding herd A's 07:00 strip and out of coverage before herd B's boundary arrived, applied herd A's strip at 07:00. The kept slots also kept `have` above herd B's boundary, so herd B's active version below it came back `stale`.
- **Reproduced first:** `test_herd.c` (new) signs boundary and config commands with the vectors' key and drives the app. Before the fix, herd A's v13 applied at 12:00 after the config naming herd B, the reboot re-enforced it, and herd B's v12 was rejected `stale`. `local/slots.json` (new, the vectors' format) failed at the `set_herd` step with `have` 13 instead of 10.
- **Fix** (`slots.c`): `slots_set_herd` drops every staged slot whose `herd_id` isn't the new herd, from RAM and flash, with no ack. The active boundary stays in force until one of the new herd applies. `slots_load` does the same after picking the active record, which covers a power cut after the config is stored and before the deletes (`app_config` stores the config first, then sets the herd). Slots without a `herd_id` stay, as insert accepts them in any herd.
- **Spec** (`protocol/README.md`): herd change bullet under Slots; `herd_id` in the config points to it. `wrong_herd` is now permanent only until the collar's config version goes up. A boundary of the new herd fetched before the config arrives is refused `wrong_herd`, and the server has to offer it again after the config. The server side is being changed in openpasture in parallel.
- **Tests**, `make -C firmware/tests/host`, 10 binaries, all pass:
  - slots: `vectors/slots.json` 12 cases unchanged. `local/slots.json` has 2 cases: the herd change drops staged, and the collar's own herd's staged slots are kept, including a move there and back. The vector runner takes a `set_herd` step and reloads each step's state with the herd set first, as `app_boot` does. Two more tests: a staged slot without `herd_id` survives a herd change, and a boot in the new herd drops the old herd's staged record from flash and still enforces the old active one.
  - herd: the story above now passes. Herd B's v14, refused `wrong_herd` before the config, is applied when offered again; herd B's v12 is applied; herd A's v13 is `wrong_herd`. With the power cut after every byte of the change (636 bytes written), the result is always the old state (herd A, slots 10 13) or the new one (herd B, slots 10), with v10 enforced: 631 old, 6 new.
  - Taking the prune out of `slots_load` makes the slot boot test fail, so that test depends on it.
- **Build:** clean, no compiler warnings. Application image 115 396 B (112.7 KB, +96 B) of 440 KB; RAM 73 776 B, unchanged. Not flashed.

### Carrier board shrunk to 65 × 62 mm
- Cody saw a lot of wasted space on the 95 × 75 mm layout. The cause: the carrier's own parts sat beside the plugged boards. The Kit, MAX-M10S and ISM330 ride ~11 mm up on their sockets, so the board under them was empty.
- Now the three plugged boards are tiled edge to edge, and every carrier part sits underneath them:
  - Kit down the left edge.
  - MAX-M10S top right.
  - ISM330 below it, turned 180° so its standoffs sit clear of the bottom-edge ports.
  - Under the Kit, between its socket rows: the buffer and switch, pull-ups, dividers, the Kit feed and two board mounts.
  - Under the M10S: the charger. Under the IMU: the ESD parts.
- **65 × 62 mm, 43 % less area.** The limit is the three boards' footprints: the M10S's 8-pin socket can't sit closer to the Kit's right-hand socket, which sets the width.
- Removed to make room:
  - The bench-only battery and NTC sockets. On the bench, a PH8 pigtail into the harness socket does the same job, and two packs can no longer be connected at once.
  - The unpopulated expansion header. The stimulus board belongs to the integrated board, and the spare GPIOs are left unconnected.
- The harness socket is now the right-angle S8B-PH-SM4-TB (LCSC C265121), so the cable enters from the edge.
- The M10S's two far-corner standoffs double as board mounts (M3 male-female standoffs into the box posts). The carrier goes into the box before the plugged boards.
- Silkscreen: the panel socket, turned sideways at the edge, gets its A+ / GND / B+ marks beside each pad, placed from the real pad positions.
- ERC clean; 91 parts, 45 nets. DRC shows only the intended butted Kit sockets, plus 131 unrouted connections. Renders reviewed top and bottom.

### Carrier board to 65 × 58.5 mm; assembled preview
- Cody still saw white space. Most of it was under the plugged boards, which the renders don't draw. `layout.py` now also writes `build/carrier_assembled.kicad_pcb`, a copy with the Kit, MAX-M10S and ISM330 outlined on the silkscreen, to render how it looks fitted. It's not for manufacture.
- The real leftover space was the connector band along the bottom edge (10.3 mm, for the PH harness socket) and the column right of the IMU. The harness socket now sits in that column, on the right edge. The panels moved to a JST-SH 3-pin (SM03B-SRSS-TB, C160403; 1 A per contact, both panels ≤ 0.46 A), so the bottom band only needs an SH socket's 6.6 mm.
- **65 × 58.5 mm**, 47 % less area than the 95 × 75 layout. This is within ~1 mm of the floor for these boards: the Kit's 55.9 mm length sets the height; the Kit, the 4 mm gap its right-hand socket needs from the M10S's socket, and the M10S's 38.1 mm set the width.
- ERC clean. DRC shows only the intended butted Kit sockets, plus the unrouted connections. Renders reviewed: bare top, assembled top, bottom.

### Test fixture guide, with pictures (2026-09-27)
- Cody asked for the test-fixture idea laid out with example parts, pictures and diagrams, as someone new to hardware. Written up in `docs/TEST-FIXTURE.md`.
- Pictures, all made from the real board:
  - Two Blender renders of a bed-of-nails fixture built around the carrier's actual 3D model (`kicad-cli pcb export glb`). The pogo pins sit at the 33 real test-pad positions (`export_pads.py` → `tp.json`); two mounting holes stand in for tooling holes.
  - Seven diagrams drawn as SVG by `diagrams.py`: how a board gets made, a fixture cross-section, a pogo pin, the test station, the test sequence, the carrier's pad map by instrument, and what the integrated board must include.
- **Caught in my own review:**
  - The first render's clear plate hid the pins, and the close-up view was a dark gap.
  - Labels were cut off in the cross-section and the integrated-board diagram.
  - An alignment pin collided with a pogo pin.
  - A price overlapped a title, and one step's text ran into the next column.
  - All fixed and re-rendered.
- Example station, parts only, ~$600–1,500: Raspberry Pi 5, Raspberry Pi Debug Probe (or J-Link), Nordic PPK2 as battery stand-in and current meter, USB bench supply as the solar stand-in, ADS1115 ADCs, USB relay board, FTDI cable, label printer, P75-class pogo pins. Prices are typical list prices from memory, not quotes. Nothing ordered.
- Recorded for the integrated board: tooling holes, a test-pad grid on one side, battery pads with a single current path for the sleep-current check, SWD/serial pads, RF test connectors (e.g. Murata MM8130), and a firmware test mode.

### HeyPCB for design, JLCPCB assembly, finishing in the garage (2026-09-27)
- Cody wants to design boards in **HeyPCB** (heypcb.ai), a browser PCB editor with an AI agent ("Inky"), live multiplayer, a 3D and enclosure view, and a gallery of ~8,800 open boards. Plans are $20–500/month, and there's a free trial for one board.
- **Checked:**
  - It edits KiCad-native project files, and you own your designs and exports (terms, section 4).
  - It runs ERC/DRC and exports Gerbers, drill files, BOM and pick-and-place.
  - Publishing to its gallery is optional and never automatic.
  - Agent prompts and design context go to third-party AI model providers. That's fine for an open design; keep it in mind for the proprietary collar later.
  - It has placed manufacturing orders and shipped to users before (the September "free board week"). Whether it offers ordering permanently is unknown.
- **Fit with our pipeline:** HeyPCB wants a schematic and a board. We generate the board from SKiDL but have no `.kicad_sch` (the known gap in DESIGN-PHASE.md). So either HeyPCB's agent redraws the schematic from our netlist and spec, or we use HeyPCB for layout and routing only. Routing is our open blocker, and it has autorouting, so Freerouting/Java may not be needed.
- Package for upload: `hardware/carrier/build/heypcb-carrier.zip`. It holds the `.kicad_pro` (JLCPCB rules), `.kicad_pcb`, netlist, spec and renders. **Caught:** a stub `.kicad_pro` reset the 0.15 mm clearance to KiCad's 0.2 mm default and gave 9 false DRC errors. The package now uses the real project file KiCad writes, so the only findings are the 2 intended socket overlaps and the unrouted connections.
- Plan: route and review in HeyPCB, export Gerbers/BOM/CPL back into git, then order at JLCPCB: 5 boards, assembled, shipped to Columbia (JLCPCB collects US import duty at checkout). The garage then fits the Kit pigtail, the breakout headers and standoffs, and the harness and panel pigtails, then does bring-up. **A current-limited bench supply is missing from `hardware/tools.md` and is needed before the first power-up.** Nothing ordered; Cody signs up and checks out himself.
- **Carrier imported into HeyPCB** (Cody's account, project `opencollar-carrier`, heypcb.ai/p/d017ac745ca9), through the dashboard's "Import board, schematic, or zip" with a board-only zip (`.kicad_pro` + `.kicad_pcb`, `build/opencollar-carrier.zip`). It opened at 65 × 58.5 mm with every part, label and test pad in place. HeyPCB's own DRC matches ours: 2 errors (the intentional butted Kit sockets), 166 unconnected (unrouted), 12 warnings. No schematic yet: HeyPCB has the board only. Not routed, not published.

### Carrier routed: HeyPCB's Inky, then the charger block redone (2026-09-27)
- Cody asked for Inky (HeyPCB's agent) to optimise the board and clean up every connection, warning and error. I gave Inky one brief: route everything, keep the fixed parts fixed, JLCPCB rules, track widths per net, GND pours and stitching, 0.5 mm around test pads, short power loops, no changes to footprints, values or nets.
- **What Inky did:**
  - It routed 163 of 166 connections in about 6 minutes, and set the power net classes (0.5 mm BAT/CHG_IN/CHG_OUT/SOLAR, 0.4 mm 3V3/EXT_3V3).
  - It then got stuck on the last 3 connections and 6 clearance errors, all at U1 (bq24074). It said its router "could not merge its result". One more turn went on an unrelated MAX-M10S footprint question.
  - It used 67 % of the $6 trial ($4). I stopped there.
- **Checked:** I pulled its board down through HeyPCB's KiCad download (`/api/projects/<id>/download/kicad`). KiCad's DRC on it matched HeyPCB's exactly. No part had moved, and every footprint, value and net matched our own build.
- **Why it was stuck:**
  - The placement, not the router. `layout.py` packed the charger's passives by block rather than by pin. The IN capacitor and the TMR resistor sat under U1 while their pins face up. CHG_IN's pin 13 ended up walled in by the TMR track and the ILIM via, with no path out.
  - Separately, Inky ran 0.5 mm power tracks straight onto the 0.5 mm-pitch pins, 0.125 mm from the neighbouring pins (the rule is 0.15).
  - Three routers failed in the same place: Inky's, a grid router of mine, and Freerouting 2.4.1 (tried with a portable Java under `build/tools/`, gitignored).
- **Fix, `hardware/carrier/finish_routing.py`:** it keeps Inky's routing everywhere else and redoes the charger block.
  - The 11 charger passives go beside the U1 pins they serve (the table in the script). For example, the IN cap sits over pin 13, the TMR resistor over pin 14 (the TMR net went from 30 mm with vias to 0.7 mm), and the OUT cap right of pins 10–11.
  - Fixed 0.25 mm fingers go on U1's power pins, so the 0.5 mm tracks start clear of the neighbouring pins.
  - Every GND pad in the block gets its own via.
  - A two-layer grid router reroutes the block: 0.05 mm grid, 45°, the board's clearances, 0.3 mm to the edge. It keeps signals mostly off the bottom layer so the GND pour under U1 stays whole, and retries route orders until every net routes.
  - Then GND stitching vias, a refill, and removal of the stubs the rip-up left, each checked with KiCad's DRC.
  - J1+J2 and J3+J4 (1×10 sockets butted into the Kit's 1×20 rows) get their courtyards pulled back to the joint and the silk at the joint removed. That includes J2's and J4's pin-1 marks, which sat mid-row at Kit pin 11. This clears the "intended" overlaps instead of leaving them as errors.
  - Vias are tented both sides, so a fixture probe that misses a test pad lands on mask.
- **I relaxed the test-pad rule I gave Inky:** it is now 0.25 mm for tracks and still 0.5 mm for vias. Tracks beside a pad are under soldermask, and the 0.5 mm keep-out was what boxed TS in.
- **Result:** `hardware/carrier/pcb/carrier.kicad_pcb`, rebuilt from the committed Inky export `pcb/heypcb/opencollar-carrier.kicad_pcb` in about 5 minutes.
  - `kicad-cli pcb drc --severity-all`: 0 violations and 0 unconnected, at every severity including warnings.
  - Power nets are 0.5 mm, apart from 0.25 mm fingers at U1 totalling 1.3 mm per net.
  - 221 vias, 77 of them GND.
  - Gerbers, drill and position files export (`build/fab/`, not committed). Renders reviewed top and bottom.
- **Not done / open:**
  - The HeyPCB project still holds Inky's version. Re-importing `pcb/carrier.kicad_pcb` there is Cody's call.
  - `layout.py` still has the old charger placement. Rerunning it regenerates an unrouted board, so the routed board is the source from here on.
  - The routing outside the charger is Inky's. It's DRC-clean but meandering in places (TS is ~74 mm, much of that the run out to the harness socket). Worth a hand pass in KiCad or HeyPCB before a production rev; fine for 5 alpha boards.
  - JLCPCB's BOM/CPL format and the rotation check on their preview happen at ordering. Nothing ordered.
- **Routed board imported into HeyPCB** at Cody's request: new project `opencollar-carrier-a2` (heypcb.ai/p/79e09bf517e0), from `pcb/carrier.kicad_pcb` + `.kicad_pro` via the dashboard import. HeyPCB can't swap the board inside an existing project, so Inky's original project `opencollar-carrier` (d017ac745ca9) is still there, untouched. HeyPCB's DRC on the import: clean, 0 airwires. The import used no Inky turns (trial at 75 %); nothing published.

### Rev A3: fuel gauge, flash, reverse protection; socket footprints corrected; fit test and JLCPCB files (2026-09-27)
- Cody approved the additions proposed earlier. Added from the chip makers' datasheets, fetched with Firecrawl:
  - **MAX17260 fuel gauge** (U6) in high-side mode: 10 mΩ sense resistor R24 with Kelvin lines, 0.1 µF BATT, 0.47 µF REG, CSPL to GND, TH to BATT. It sits on the main I2C bus at 0x36, with ALRT to P0.00 and a 100 k pull-up.
  - **W25Q128JV 16 MB flash** (U7) on P0.01–P0.04 over SPI. /WP and /HOLD go to VCC, /CS has a 100 k pull-up, 0.1 µF decoupling.
  - **AO3401A P-FET** (Q1) for reverse-battery protection, placed before the gauge so a reversed pack never reaches its pins.
  - **Charger resistors to JLCPCB basic values:** ISET 887 Ω → 1 kΩ, ILIM 3.24 kΩ → 4.7 kΩ, TMR 71.5 kΩ → 68 kΩ.
  - The battery path is now harness BAT_PACK → Q1 → BAT_CELL → R24 → BAT. ERC is clean: 100 parts, 53 nets. Every existing part keeps its reference.
- **Stock problem:** the MAX17260 is at **0 at JLCPCB and LCSC** (both listings, C350946 and C5280558). Every other high-side gauge I checked (MAX17262, BQ27220, MAX17055) is also at or near 0. The design keeps the MAX17260. At ordering the choice is JLCPCB Global Sourcing (DigiKey/Mouser), or leaving U6 off: the board runs without it, since R24 carries the current. It's in SPEC.md question 14.
- **Caught in the datasheet review: the socket footprints were mirrored.**
  - The hanxia drawing gives no land pattern. JLCPCB's own footprints for all four sockets (1 × 4, 8, 9, 10; EasyEDA library) put pin 1's leg on the other side from KiCad's `Pin1Left`, which the board used.
  - On the even-length sockets a mirror can't be fixed by turning the part round, so JLCPCB couldn't have soldered J1–J4, J8 or J9 down.
  - All seven sockets are now `Pin1Right`, which fits JLCPCB's footprints to 0.000 mm. Each pad keeps its row position and net and moves to the other side of the socket.
  - The drawing confirms the 1 × 10 body is 25.40 mm long, so two butt into a continuous 1 × 20.
- **Other checks:**
  - bq24074 pinout against TI's table: all 16 pins match. The land pattern matches TI's RGT0016C example (1.68 mm thermal pad). TI asks for vias in the thermal pad to be filled or tented; ours are open 0.3 mm vias, a minor solder-wicking risk.
  - AO3401A pins in JLCPCB's symbol: G = 1, S = 2, D = 3, matching ours. B5819W pin 1 is the cathode, matching ours.
  - Stock: bq24074 795 (816 the day before); S8B harness connector 19,343; flash 59k and FET 884k, both basic parts.
- **Routing.** Moving every socket pad meant re-routing nearly all the plug-in board connections. My grid router, routing one net at a time and retrying orders, left 16 nets open after a 35-minute attempt. The pipeline in `finish_routing.py` is now:
  - Inky's board is brought up to the schematic: parts, values, footprints, nets.
  - The charger stays placed by pin. The new parts are placed: flash under the M10S, gauge column on the right edge.
  - Fixed copper goes at U6's 0.4 mm-pitch pins: REG into C10, a Kelvin CSPH line along the board edge into R24, and ALRT, SDA and SCL out to the left.
  - Every small part's GND pad gets its own via before routing. This was caught when U3's input cap C8 was left on a GND sliver between the new flash lines.
  - **Freerouting** (single-threaded; the same result every run) routes around Inky's surviving copper. The grid router then finishes what it can't, with **rip-up and reroute**: EXT_SDA was walled in by the Kit socket column and routed by moving seven other nets.
  - Last come GND stitching, joining cut-off pour pieces (also with rip-up), and stub cleanup, all checked against KiCad's DRC.
  - R5 (the unfitted TS resistor) moved beside C1, and J5's GND hole is solid to the pour.
- **Result:** `pcb/carrier.kicad_pcb`, rev A3.
  - `kicad-cli pcb drc --severity-all`: **0 violations, 0 unconnected.**
  - The board matches the schematic on all 53 nets, and Inky's placement changed only where intended.
  - 1,323 tracks, 335 vias (140 GND). Power paths are 0.5 mm; the 0.2 mm lengths are the gauge's sense lines.
  - Renders reviewed top and bottom.
- **Fit test:** `fit_test.py` writes `build/carrier-fit-test.pdf`, a 1:1 print with every socket contact circled, the three plugged boards outlined and a 50 mm scale bar. Cody prints it at 100 % and lays the Kit, MAX-M10S and ISM330 on it.
- **JLCPCB files:** `jlc_files.py` writes the BOM (33 lines), the placement file (59 parts) and the Gerbers + drill zip into `build/fab/`. For each part it fetches JLCPCB's own footprint and computes the rotation and offset from the pads. All 59 fit (worst 0.2 mm, land-pattern differences on SOT-23), with no mirrored parts. It still needs checking in JLCPCB's placement preview at quote time.
- Not done / open:
  - HeyPCB still has the A2 board. The A3 board isn't uploaded there; that's Cody's call.
  - The router's work outside the charger meanders in places. It's DRC-clean; a hand pass before production would tidy it.
  - Nothing ordered or pushed.

### Carrier explained for Cody (2026-09-27)
- Cody asked for every component explained, and how the board fits the assembled collar. Written up as `docs/CARRIER-EXPLAINED.md`, with the rev A3 top render labelled by function (`docs/images/carrier/carrier-labelled.png`).
- It covers: the plug-in boards; the power chain (panels, diodes, charger, battery guard, fuel gauge, Kit feed); the flash; everything that leaves the box (harness, cue ports, bus buffer, power switch, ESD); the mounting holes and test pads; and the V1-alpha collar layout (test box on the crest, ear pods, battery module under the throat).
- Where to pick up next: Cody prints the fit test and gets a JLCPCB quote (SPEC.md questions 12–14), and decides on the MAX17260 sourcing. Nothing ordered or pushed.

## 2026-10-01

### Licences added
- **Why now:** a builder asked on LinkedIn when the repo would have licences, because they want to port the firmware to Rust. Until today the repo had no licence files, so it was all rights reserved.
- **Cody asked for** licences as permissive as possible, with protection against someone taking the collar and keeping it closed. Chosen to match:
  - Firmware, scripts and the protocol: **Apache-2.0** (`LICENSE`).
  - Hardware and CAD in `hardware/` and `mechanical/`: **CERN-OHL-W-2.0** (`LICENSES/`), changed from the CERN-OHL-P planned in `STRATEGY.md`. Anyone can build and sell the boards; a shipped modified version must publish its changes to these files. Hardware starts at W because loosening later is possible and tightening a released version isn't.
  - Docs, photos and renders: **CC BY 4.0**.
  - `NOTICE`: copyright Cody Menefee (openpasture); the names openpasture and OpenCollar and the logo aren't licensed.
  - `CONTRIBUTING.md`: contributions take the licence of the files they touch, and contributors grant openpasture the right to relicense them, so outside improvements can go into openpasture's own collars.
- The carrier's bottom silkscreen now reads `CERN-OHL-W  2026-09-27` (in `layout.py`, `pcb/carrier.kicad_pcb` and the HeyPCB import). Text only; no copper changed. `SPEC.md`, `BOARD-DESIGN.md` and `STRATEGY.md` updated to match.
- Still open: the trademark search on "OpenCollar" (`STRATEGY.md`, "Check the name").

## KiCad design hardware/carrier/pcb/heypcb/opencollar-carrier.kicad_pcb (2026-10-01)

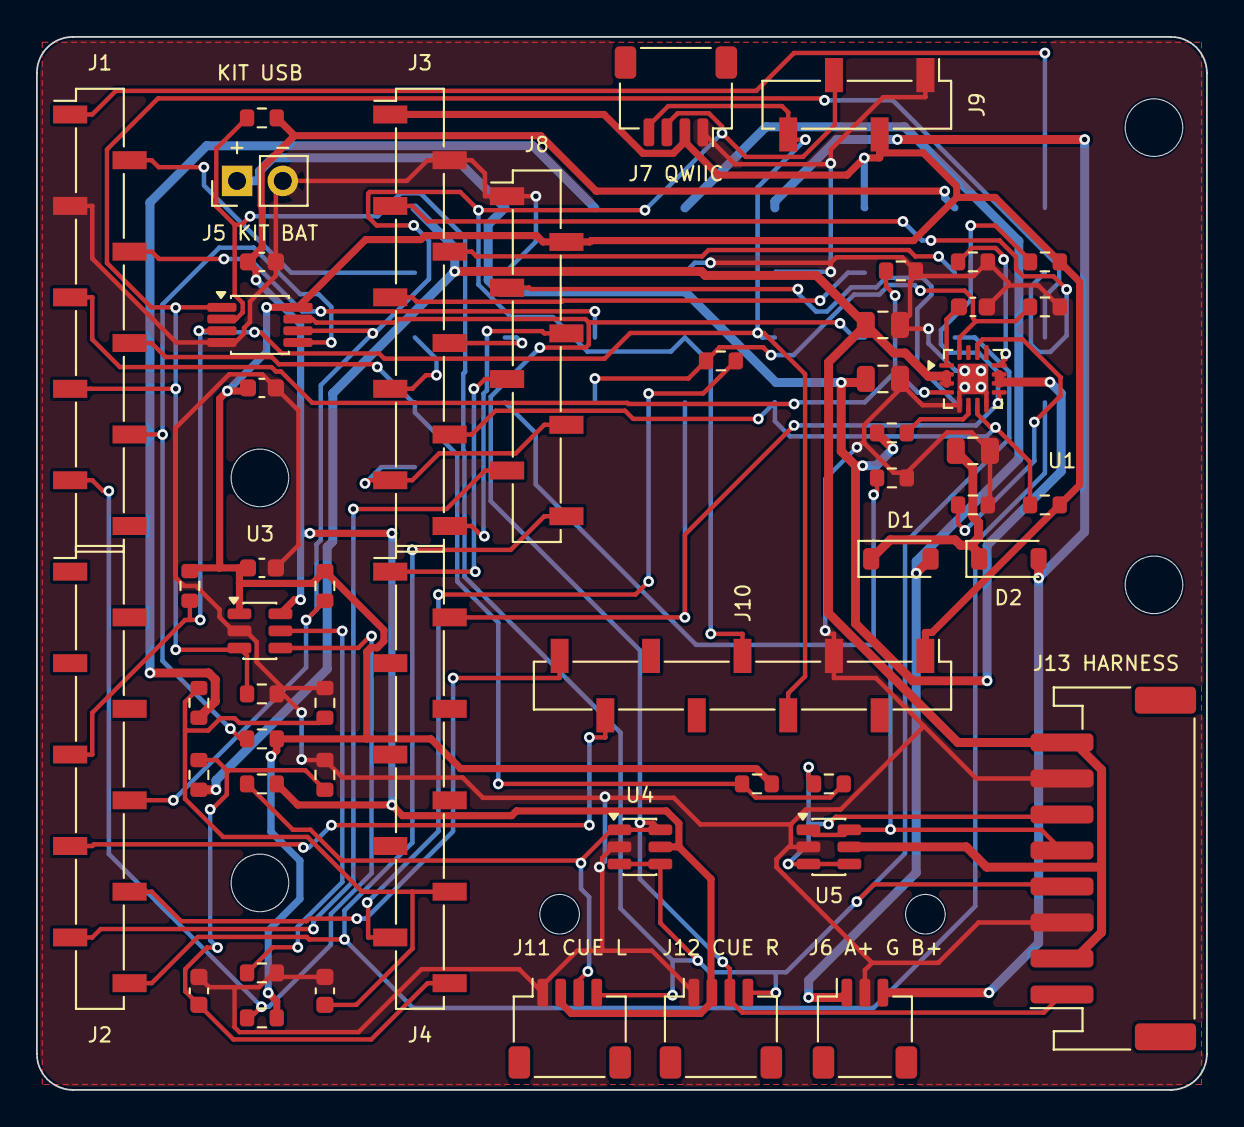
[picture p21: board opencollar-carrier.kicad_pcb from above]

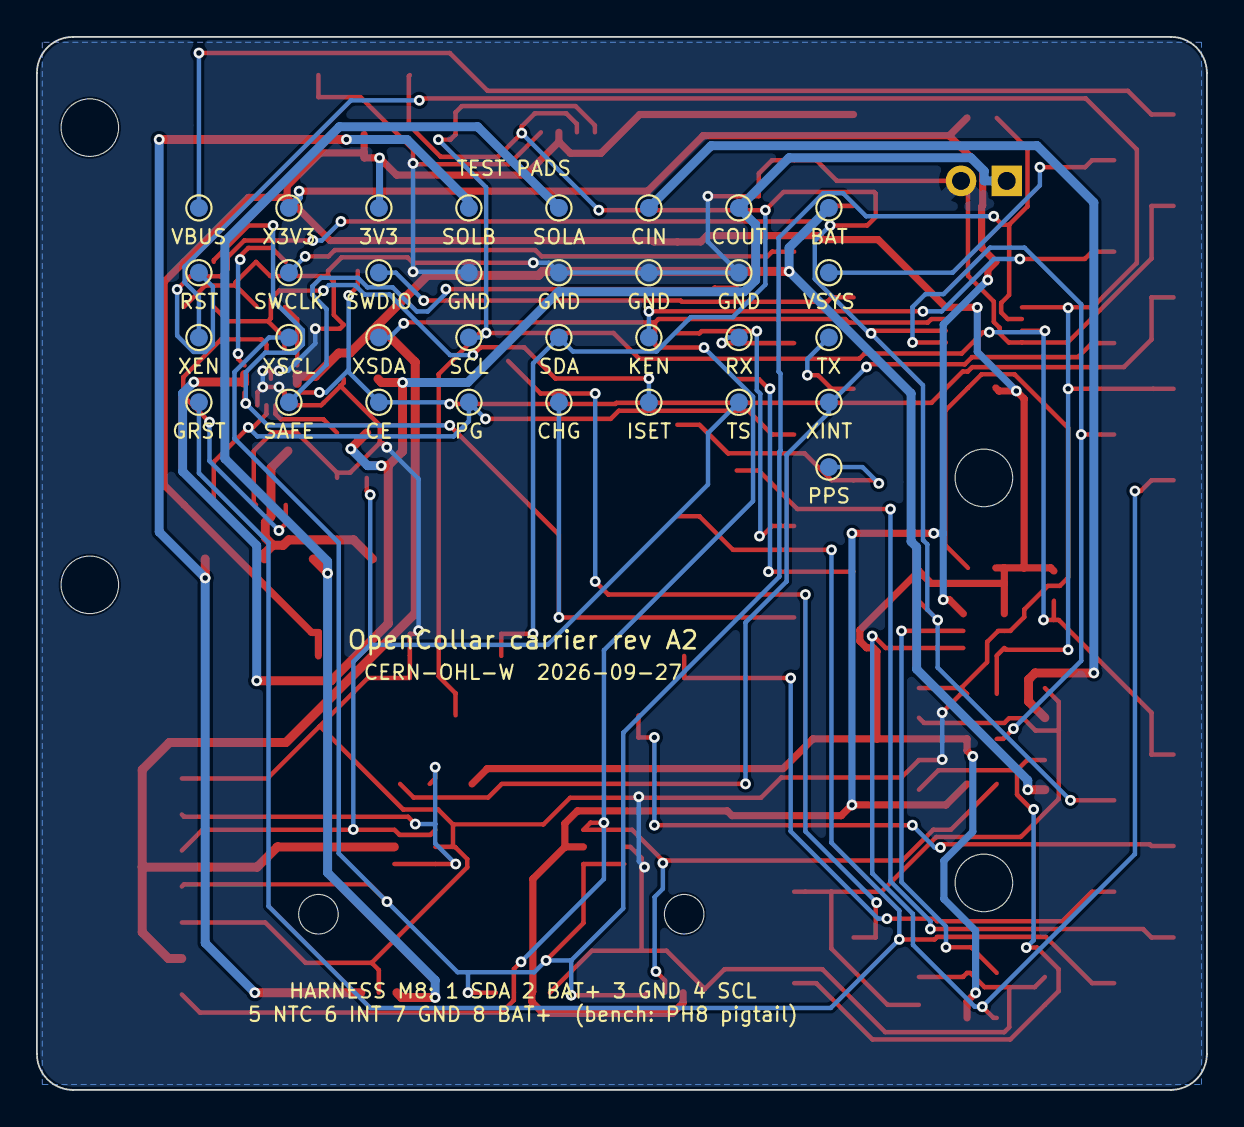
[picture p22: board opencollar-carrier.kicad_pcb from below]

Board: 2 copper layers, 65.0 x 58.5 mm, 91 parts (33 on the bottom side), 45 nets.

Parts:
C1: 10n; C_0603_1608Metric
C2, C3, C4: 10u/25V; C_0805_2012Metric
C5, C6, C7: 100n; C_0603_1608Metric
C8, C9: 1u; C_0603_1608Metric
D1, D2: B5819W; D_SOD-123
H1, H2, H3, H4: MountingHole; MountingHole_3.2mm_M3
H5, H6: MountingHole; MountingHole_2.2mm_M2
J1: Kit 1-10; PinSocket_1x10_P2.54mm_Vertical_SMD_Pin1Left
J2: Kit 11-20; PinSocket_1x10_P2.54mm_Vertical_SMD_Pin1Left
J3: Kit 40-31; PinSocket_1x10_P2.54mm_Vertical_SMD_Pin1Left
J4: Kit 30-21; PinSocket_1x10_P2.54mm_Vertical_SMD_Pin1Left
J5: Kit J2 feed; PinHeader_1x02_P2.54mm_Vertical
J6: Panels A/GND/B; JST_SH_SM03B-SRSS-TB_1x03-1MP_P1.00mm_Horizontal
J7: Qwiic spare; JST_SH_SM04B-SRSS-TB_1x04-1MP_P1.00mm_Horizontal
J8: M10S J5; PinSocket_1x08_P2.54mm_Vertical_SMD_Pin1Left
J9: M10S J3; PinSocket_1x04_P2.54mm_Vertical_SMD_Pin1Left
J10: ISM330; PinSocket_1x09_P2.54mm_Vertical_SMD_Pin1Left
J11: Cue L; JST_SH_SM04B-SRSS-TB_1x04-1MP_P1.00mm_Horizontal
J12: Cue R; JST_SH_SM04B-SRSS-TB_1x04-1MP_P1.00mm_Horizontal
J13: Harness M8; JST_PH_S8B-PH-SM4-TB_1x08-1MP_P2.00mm_Horizontal
R1, R5, R17: 10k; R_0603_1608Metric
R2: 887; R_0603_1608Metric
R3: 3.24k; R_0603_1608Metric
R4: 71.5k; R_0603_1608Metric
R6, R7, R8, R13, R16, R20, R21, R23: 100k; R_0603_1608Metric
R9, R10, R11: 1M; R_0603_1608Metric
R12: 200k; R_0603_1608Metric
R14, R15, R18, R19: 4.7k; R_0603_1608Metric
R22: 1k; R_0603_1608Metric
TP1: BAT; TestPoint_Pad_D1.0mm
TP2: CHG_OUT; TestPoint_Pad_D1.0mm
TP3: CHG_IN; TestPoint_Pad_D1.0mm
TP4: SOLAR_A; TestPoint_Pad_D1.0mm
TP5: SOLAR_B; TestPoint_Pad_D1.0mm
TP6: 3V3; TestPoint_Pad_D1.0mm
TP7: EXT_3V3; TestPoint_Pad_D1.0mm
TP8: KIT_VBUS; TestPoint_Pad_D1.0mm
TP9: KIT_VSYS; TestPoint_Pad_D1.0mm
TP10, TP11, TP12, TP13: GND; TestPoint_Pad_D1.0mm
TP14: SWDIO; TestPoint_Pad_D1.0mm
TP15: SWCLK; TestPoint_Pad_D1.0mm
TP16: RESET; TestPoint_Pad_D1.0mm
TP17: UART_TX; TestPoint_Pad_D1.0mm
TP18: UART_RX; TestPoint_Pad_D1.0mm
TP19: KIT_EN; TestPoint_Pad_D1.0mm
TP20: I2C_SDA; TestPoint_Pad_D1.0mm
TP21: I2C_SCL; TestPoint_Pad_D1.0mm
TP22: EXT_SDA; TestPoint_Pad_D1.0mm
TP23: EXT_SCL; TestPoint_Pad_D1.0mm
TP24: EXT_EN; TestPoint_Pad_D1.0mm
TP25: EXT_INT; TestPoint_Pad_D1.0mm
TP26: TS; TestPoint_Pad_D1.0mm
TP27: ISET; TestPoint_Pad_D1.0mm
TP28: CHG_STAT; TestPoint_Pad_D1.0mm
TP29: CHG_PGOOD; TestPoint_Pad_D1.0mm
TP30: CHG_CE; TestPoint_Pad_D1.0mm
TP31: GNSS_SAFEBOOT; TestPoint_Pad_D1.0mm
TP32: GNSS_RESET_N; TestPoint_Pad_D1.0mm
TP33: GNSS_PPS; TestPoint_Pad_D1.0mm
U1: BQ24074RGT; VQFN-16-1EP_3x3mm_P0.5mm_EP1.68x1.68mm
U2: TCA4307; VSSOP-8_3x3mm_P0.65mm
U3: TPS2553; SOT-23-6
U4, U5: USBLC6-2SC6; SOT-23-6

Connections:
3V3: C7.1, C8.1, J3.1, J7.2, J8.2, J9.2, J10.1, R7.2, R8.2, R14.2, R15.2, R17.2, R21.2, R23.2, TP6.1, U2.8, U3.1
BAT: C4.1, J13.2, J13.8, R9.1, TP1.1, U1.2, U1.3, U5.5
CHG_CE: J1.5, R6.1, TP30.1, U1.4
CHG_IN: C2.1, D1.1, D2.1, R11.1, TP3.1, U1.13
CHG_OUT: C3.1, J5.1, R1.1, TP2.1, U1.10, U1.11
CHG_PGOOD: J3.8, R8.1, TP29.1, U1.7
CHG_STAT: J4.2, R7.1, TP28.1, U1.9
EXT_3V3: C9.1, J11.2, J12.2, R18.2, R19.2, TP7.1, U3.6, U4.5
EXT_EN: J1.7, R16.1, TP24.1, U2.1, U3.3
EXT_FAULT: J1.9, R21.1, U3.4
EXT_INT: J1.6, R22.2, R23.1, TP25.1
EXT_INT_RAW: J13.6, R22.1, U5.3, U5.4
EXT_READY: J1.8, R17.1, U2.5
EXT_SCL: J11.4, J12.4, J13.4, R19.1, TP23.1, U2.2, U4.3, U4.4
EXT_SDA: J11.3, J12.3, J13.1, R18.1, TP22.1, U2.7, U4.1, U4.6
GND: C1.2, C2.2, C3.2, C4.2, C5.2, C6.2, C7.2, C8.2, C9.2, J1.3, J3.2, J5.2, J6.2, J7.1, J8.1, J9.1, J10.3, J11.1, J12.1, J13.3, J13.7, R2.2, R3.2, R4.2, R5.2, R6.2, R10.2, R12.2, R16.2, R20.2, TP10.1, TP11.1, TP12.1, TP13.1, U1.5, U1.8, U1.17, U2.4, U3.2, U4.2, U5.2
GNSS_EXTINT: J2.9, J8.7
GNSS_PPS: J3.9, J8.6, TP33.1
GNSS_RESET_N: J2.10, J8.8, TP32.1
GNSS_RXD: J4.1, J8.5
GNSS_SAFEBOOT: J8.3, TP31.1
GNSS_TXD: J3.10, J8.4
I2C_SCL: J2.5, J7.4, J9.4, J10.4, R15.1, TP21.1, U2.3
I2C_SDA: J2.6, J7.3, J9.3, J10.5, R14.1, TP20.1, U2.6
IMU_INT1: J2.7, J10.8
IMU_INT2: J2.8, J10.9
ISET: R2.1, R13.1, TP27.1, U1.16
ISET_SENSE: J4.9, R13.2
KIT_EN: J1.4, TP19.1
KIT_VBUS: J1.1, TP8.1
KIT_VSYS: J1.2, TP9.1
unnamed: R1.2, U1.6
unnamed: R3.1, U1.12
unnamed: R4.1, U1.14
unnamed: R20.1, U3.5
RESET: J3.3, TP16.1
SOLAR_A: D1.2, J6.1, TP4.1
SOLAR_B: D2.2, J6.3, TP5.1
SWCLK: J3.4, TP15.1
SWDIO: J3.5, TP14.1
TS: C1.1, J13.5, R5.1, TP26.1, U1.1, U5.1, U5.6
UART_RX: J3.6, TP18.1
UART_TX: J3.7, TP17.1
VBAT_SENSE: C5.1, J4.10, R9.2, R10.1
VIN_SENSE: C6.1, J4.8, R11.2, R12.1

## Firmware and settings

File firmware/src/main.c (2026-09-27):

/*
 * OpenCollar 0.2: GNSS fix -> slots and geofence -> audio cue, logged over
 * serial, with provisioning and bench commands on the same serial port.
 *
 * Boot: provisioning, config and slots come from flash (NVS); the latest
 * active boundary is enforced at once, staged ones wait for the first GNSS
 * fix. No boundary means no fence and no cues. GNSS time is the only clock
 * for boundary activation. Everything else is in app.c, which host tests
 * drive the same way. Boundary download over LTE waits for the SIM; until
 * then a signed command can be pasted on the console (`boundary <command>`).
 */
#include <zephyr/kernel.h>
#include <zephyr/logging/log.h>
#include <zephyr/sys/printk.h>
#include <modem/lte_lc.h>
#include <modem/nrf_modem_lib.h>
#include <nrf_modem_gnss.h>

#include "app.h"
#include "boundary.h"
#include "buzzer.h"
#include "console.h"
#include "store.h"

LOG_MODULE_REGISTER(opencollar, LOG_LEVEL_INF);

static const struct geofence_config geofence_defaults = {
	.warn_m = 5.0,
	.hysteresis_m = 1.0,
	.max_accuracy_m = 10.0,
};

static const struct cue_config cue_cfg = {
	.warn_freq_hz = 2730, /* Buzzer's resonant frequency: loudest */
	.outside_freq_hz = 1000,
	.beep_ms = 300,
	.max_active_ms = 20000,
	.rest_ms = 30000,
	.outside_max_ms = 10000,
};

struct fix {
	bool valid;
	bool has_time;
	double lat;
	double lon;
	float accuracy;
	uint8_t sats_tracked;
	uint8_t sats_in_fix;
	int64_t utc;
};

K_MSGQ_DEFINE(fix_q, sizeof(struct fix), 4, 8);
static struct k_poll_signal console_sig = K_POLL_SIGNAL_INITIALIZER(console_sig);

/* Everything the collar knows, in static RAM (see BUILD-LOG for the budget) */
static struct app app;
static char reply[256];
static uint32_t store_errors_seen;

static void gnss_event_handler(int event)
{
	struct nrf_modem_gnss_pvt_data_frame pvt;
	struct fix f = {0};

	if (event != NRF_MODEM_GNSS_EVT_PVT) {
		return;
	}
	if (nrf_modem_gnss_read(&pvt, sizeof(pvt), NRF_MODEM_GNSS_DATA_PVT) != 0) {
		return;
	}

	for (int i = 0; i < NRF_MODEM_GNSS_MAX_SATELLITES; i++) {
		if (pvt.sv[i].sv == 0) {
			continue;
		}
		f.sats_tracked++;
		if (pvt.sv[i].flags & NRF_MODEM_GNSS_SV_FLAG_USED_IN_FIX) {
			f.sats_in_fix++;
		}
	}

	f.valid = pvt.flags & NRF_MODEM_GNSS_PVT_FLAG_FIX_VALID;
	f.lat = pvt.latitude;
	f.lon = pvt.longitude;
	f.accuracy = pvt.accuracy;
	if (f.valid) {
		/* The fix's own UTC: the clock for boundary activation */
		f.has_time = true;
		f.utc = proto_time_civil(pvt.datetime.year, pvt.datetime.month, pvt.datetime.day,
					 pvt.datetime.hour, pvt.datetime.minute,
					 pvt.datetime.seconds);
	}

	/* Drop the fix if the main loop is behind; the next one is a second away */
	k_msgq_put(&fix_q, &f, K_NO_WAIT);
}

static int gnss_start(void)
{
	int err;

	err = nrf_modem_lib_init();
	if (err) {
		LOG_ERR("Modem library init failed: %d", err);
		return err;
	}

	err = lte_lc_system_mode_set(LTE_LC_SYSTEM_MODE_LTEM_GPS, LTE_LC_SYSTEM_MODE_PREFER_AUTO);
	if (err) {
		LOG_ERR("System mode set failed: %d", err);
		return err;
	}

	/* GNSS only until the SIM is in: LTE isn't needed for local fencing */
	err = lte_lc_func_mode_set(LTE_LC_FUNC_MODE_ACTIVATE_GNSS);
	if (err) {
		LOG_ERR("Failed to activate GNSS: %d", err);
		return err;
	}

	err = nrf_modem_gnss_event_handler_set(gnss_event_handler);
	if (!err) {
		err = nrf_modem_gnss_fix_interval_set(1);
	}
	if (!err) {
		err = nrf_modem_gnss_start();
	}
	if (err) {
		LOG_ERR("GNSS start failed: %d", err);
	}
	return err;
}

static void log_ack(const struct slot_ack *ack)
{
	char at[24] = "-";

	if (ack->has_at) {
		proto_time_format(ack->at, at, sizeof(at));
	}
	LOG_INF("ack v%u %s%s%s at %s (%u pending)", ack->version, ack_status_str(ack->status),
		ack->code ? " " : "", reject_str(ack->code), at, app.acks.n);
}

static void check_store(void)
{
	uint32_t errors = app.slots.store_errors + app.cfg.store_errors;

	if (errors != store_errors_seen) {
		LOG_WRN("Flash writes failed: %u so far", errors);
		store_errors_seen = errors;
	}
}

static void handle_fix(const struct fix *f)
{
	static int64_t last_no_fix_log;
	int64_t now = k_uptime_get();
	struct app_fix_in in = {
		.valid = f->valid,
		.lat = f->lat,
		.lon = f->lon,
		.accuracy_m = f->accuracy,
		.has_time = f->has_time,
		.utc = f->utc,
	};
	struct app_fix_out out = app_fix(&app, &in, now);
	struct episode ep;

	if (out.applied) {
		LOG_INF("event: staged boundary v%u now in force", out.ack.version);
		log_ack(&out.ack);
		check_store();
	}

	if (!f->valid) {
		if (now - last_no_fix_log >= 10000) {
			last_no_fix_log = now;
			LOG_INF("searching: %u tracked, %u in fix", f->sats_tracked, f->sats_in_fix);
		}
		return;
	}

	if (!out.fenced) {
		LOG_INF("fix %.6f,%.6f acc=%.1fm sats=%u (no boundary)", f->lat, f->lon,
			(double)f->accuracy, f->sats_in_fix);
		return;
	}

	if (out.cmd.active) {
		buzzer_play(out.cmd.freq_hz, out.cmd.volume, out.cmd.duration_ms);
	}

	LOG_INF("fix %.6f,%.6f acc=%.1fm sats=%u v%u state=%s margin=%.1fm ring=%d%s%s cue=%s vol=%u",
		f->lat, f->lon, (double)f->accuracy, f->sats_in_fix, out.version,
		geofence_state_str(out.r.state), out.r.margin_m, out.r.nearest_ring,
		out.r.degraded ? " (degraded)" : "",
		app.cue.mode == CUE_MODE_TRACK ? " (track)" : (app.cue.armed ? "" : " (unarmed)"),
		out.cmd.active ? cue_kind_str(out.cmd.kind) : "off", out.cmd.volume);

	if (out.r.changed) {
		LOG_INF("event: state -> %s", geofence_state_str(out.r.state));
	}
	while (cue_take_episode(&app.cue, &ep)) {
		LOG_INF("episode: %s ring=%d cues=%u max=%u min_margin=%.1fm %lld ms",
			episode_outcome_str(ep.outcome), ep.ring, ep.cues, ep.max_level,
			ep.min_margin_m, ep.end - ep.start);
	}
}

static void handle_line(void)
{
	size_t len;
	bool overflow;
	const char *line = console_line(&len, &overflow);
	uint32_t acks_before = app.acks.n;
	uint32_t version_before = app.fence ? app.fence->version : 0;
	bool fenced_before = app.fence != NULL;

	if (!line) {
		return;
	}
	app_line(&app, line, len, overflow, k_uptime_get(), reply, sizeof(reply));
	console_release();
	if (reply[0]) {
		printk("%s\n", reply);
	}
	if (app.acks.n != acks_before && app.acks.n > 0) {
		log_ack(&app.acks.q[app.acks.n - 1]);
	}
	if (app.fence && (!fenced_before || app.fence->version != version_before)) {
		LOG_INF("event: boundary v%u in force: %d rings, %d vertices", app.fence->version,
			app.fence->rings, app.fence->n);
	} else if (!app.fence && fenced_before) {
		LOG_INF("event: no boundary: no cues");
	}
	check_store();
}

static void log_boot_state(void)
{
	const struct slot_hdr *act = slots_active(&app.slots);
	uint32_t staged = app.slots.n - (act ? 1 : 0);

	if (!app.prov.ok) {
		LOG_INF("Not provisioned: GNSS only. Paste the card: provision {...}");
		return;
	}
	LOG_INF("Collar %s, herd %s, config %s", app.prov.collar_id.s, app_herd(&app)->s,
		app.cfg.has ? "stored" : "none");
	if (act && app.fence) {
		LOG_INF("Boundary v%u enforced from flash: %d rings, %d vertices%s", act->version,
			app.fence->rings, app.fence->n,
			(act->flags & SLOT_F_TRACK) ? ", track mode" : "");
	} else {
		LOG_INF("No boundary: no cues");
	}
	if (staged) {
		LOG_INF("%u staged boundaries wait for the first GNSS fix", staged);
	}
	if (app.acks.n) {
		LOG_INF("%u acks pending", app.acks.n);
	}
}

int main(void)
{
	struct fix f;
	int err;
	struct k_poll_event events[] = {
		K_POLL_EVENT_STATIC_INITIALIZER(K_POLL_TYPE_MSGQ_DATA_AVAILABLE,
						K_POLL_MODE_NOTIFY_ONLY, &fix_q, 0),
		K_POLL_EVENT_STATIC_INITIALIZER(K_POLL_TYPE_SIGNAL, K_POLL_MODE_NOTIFY_ONLY,
						&console_sig, 0),
	};

	LOG_INF("OpenCollar %s starting", APP_FW_VERSION);

	err = store_init();
	if (err) {
		LOG_ERR("Flash storage unavailable (%d): nothing will be kept over a reboot", err);
	}

	app_init(&app, &cue_cfg, &geofence_defaults);
	app_boot(&app, k_uptime_get());
	log_boot_state();

#ifdef CONFIG_OPENCOLLAR_BENCH_BOUNDARY
	if (app_bench(&app, boundary_vertices, ARRAY_SIZE(boundary_vertices), k_uptime_get())) {
		LOG_INF("Bench boundary loaded as v0: %u vertices",
			(unsigned)ARRAY_SIZE(boundary_vertices));
	}
#endif

	err = console_init(&console_sig);
	if (err) {
		LOG_ERR("Console input unavailable: %d", err);
	}

	if (buzzer_init() == 0) {
		/* Short chirp so you know the cue path works at boot (not a cue) */
		buzzer_play(cue_cfg.warn_freq_hz, 2, 150);
	}

	if (gnss_start() == 0) {
		LOG_INF("GNSS started");
	}

	while (true) {
		k_poll(events, ARRAY_SIZE(events), K_FOREVER);

		if (events[0].state == K_POLL_STATE_MSGQ_DATA_AVAILABLE) {
			while (k_msgq_get(&fix_q, &f, K_NO_WAIT) == 0) {
				handle_fix(&f);
			}
		}
		if (events[1].state == K_POLL_STATE_SIGNALED) {
			k_poll_signal_reset(&console_sig);
			handle_line();
		}
		events[0].state = K_POLL_STATE_NOT_READY;
		events[1].state = K_POLL_STATE_NOT_READY;
	}

	return 0;
}

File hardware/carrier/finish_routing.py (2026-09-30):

"""Finish the carrier's routing: Inky's HeyPCB board brought up to the current schematic.

    uv run python schematic.py      # build/carrier.net, read below
    kicad-python finish_routing.py pcb/heypcb/opencollar-carrier.kicad_pcb pcb/carrier.kicad_pcb

Needs Freerouting 2.4 and a Java 25 runtime in build/tools (gitignored), from
github.com/freerouting/freerouting/releases and api.adoptium.net (see DESIGN-PHASE.md).

HeyPCB's agent (Inky) routed rev A2. Since then the board has changed under it, so this
brings Inky's board up to the schematic and routes what changed:
  1. new parts, values, nets and footprints from build/carrier.net (rev A3: fuel gauge,
     flash, reverse protection, basic-value charger resistors, Pin1Right sockets), new
     parts placed per A3_PARTS;
  2. the charger's passives re-placed beside the U1 pins they serve (CHARGER): packed by
     block, the IN cap and TMR resistor had sat under the chip with their pins on top;
  3. copper cleared wherever it no longer fits (changed nets, re-footprinted sockets, the
     charger block, the new parts); fixed copper at the fine-pitch parts (U1 0.5 mm,
     U6 0.4 mm), so no router has to find its way out of their pins; a GND via at every
     small part's GND pad, so no decoupling cap depends on the pour reaching it;
  4. Freerouting routes what's open around the copper that stayed; a two-layer grid
     router (0.05 mm grid, 45-degree moves, rip-up and reroute) finishes what it can't;
  5. GND stitching, joining any pour piece the routing cut off, stub cleanup, each
     checked with KiCad's own DRC.
It also pulls J1-J4's courtyards and silk back where the sockets butt end to end.
Result: kicad-cli DRC with every severity reports nothing.
"""
import heapq
import math
import os
import sys

import numpy as np
import pcbnew

G = 0.05                      # grid, mm
CLR = 0.15                    # copper clearance
EPS = 0.03                    # grid slack: tracks run between grid points
EDGE_CLR = 0.3
TP_CLR = 0.5                  # vias to bottom test pads: a probe that misses mustn't land on bare copper
TP_TRACK_CLR = 0.25           # tracks to test pads (they're under soldermask)
HOLE_CLR = 0.25               # hole to hole, copper to NPTH
VIA_D, VIA_DRILL = 0.6, 0.3
VIA_COST = 2.5                # mm-equivalent
TURN_COST = 0.3
NECK_W, NECK_R = 0.25, 1.0    # power tracks may narrow to 0.25 mm within 1 mm of U1's pins
NECK = {"U1": 0.25, "U6": 0.2}  # fine-pitch parts and the width tracks may narrow to at their pins
                                # (U6 is 0.4 mm pitch: 0.2 mm leaves 0.2 mm to the next pin)
WIDTH = {"BAT": 0.5, "BAT_PACK": 0.5, "BAT_CELL": 0.5, "CHG_IN": 0.5, "CHG_OUT": 0.5, "SOLAR_A": 0.5, "SOLAR_B": 0.5,
         "3V3": 0.4, "EXT_3V3": 0.4}
LAYERS = (pcbnew.F_Cu, pcbnew.B_Cu)

mm, nm = pcbnew.ToMM, pcbnew.FromMM


def V(x, y):
    return pcbnew.VECTOR2I(nm(float(x)), nm(float(y)))


# ---------------------------------------------------------------- geometry

def seg_dist(px, py, ax, ay, bx, by):
    """Distance from points (arrays) to segment a-b."""
    dx, dy = bx - ax, by - ay
    L2 = dx * dx + dy * dy
    t = np.zeros_like(px) if L2 == 0 else np.clip(((px - ax) * dx + (py - ay) * dy) / L2, 0, 1)
    return np.hypot(px - (ax + t * dx), py - (ay + t * dy))


def rect_dist(px, py, cx, cy, w, h, rot):
    a = math.radians(rot)
    c, s = math.cos(a), math.sin(a)
    lx = (px - cx) * c - (py - cy) * s
    ly = (px - cx) * s + (py - cy) * c
    qx, qy = np.abs(lx) - w / 2, np.abs(ly) - h / 2
    return np.hypot(np.maximum(qx, 0), np.maximum(qy, 0)) + np.minimum(np.maximum(qx, qy), 0)


class Shape:
    """One piece of copper on one or both layers: 'seg' (with width), 'rect' or 'circle'."""

    def __init__(self, item, net, layers, kind, **g):
        self.item, self.net, self.layers, self.kind, self.g = item, net, layers, kind, g

    def bbox(self):
        g = self.g
        if self.kind == "seg":
            r = g["w"] / 2
            return min(g["ax"], g["bx"]) - r, min(g["ay"], g["by"]) - r, max(g["ax"], g["bx"]) + r, max(g["ay"], g["by"]) + r
        if self.kind == "circle":
            return g["x"] - g["r"], g["y"] - g["r"], g["x"] + g["r"], g["y"] + g["r"]
        r = math.hypot(g["w"], g["h"]) / 2
        return g["x"] - r, g["y"] - r, g["x"] + r, g["y"] + r

    def dist(self, px, py):
        """Distance from points to this copper's edge (negative inside)."""
        g = self.g
        if self.kind == "seg":
            return seg_dist(px, py, g["ax"], g["ay"], g["bx"], g["by"]) - g["w"] / 2
        if self.kind == "circle":
            return np.hypot(px - g["x"], py - g["y"]) - g["r"]
        return rect_dist(px, py, g["x"], g["y"], g["w"], g["h"], g["rot"])


def pad_shape(p):
    q, s = p.GetPosition(), p.GetSize()
    layers = tuple(L for L in LAYERS if p.IsOnLayer(L))
    x, y, w, h = mm(q.x), mm(q.y), mm(s.x), mm(s.y)
    if p.GetShape() == pcbnew.PAD_SHAPE_CIRCLE:
        return Shape(p, p.GetNetname(), layers, "circle", x=x, y=y, r=w / 2)
    return Shape(p, p.GetNetname(), layers, "rect", x=x, y=y, w=w, h=h, rot=p.GetOrientationDegrees())


def track_shapes(t):
    if t.GetClass() == "PCB_VIA":
        q = t.GetPosition()
        return [Shape(t, t.GetNetname(), LAYERS, "circle", x=mm(q.x), y=mm(q.y), r=mm(t.GetWidth(pcbnew.F_Cu)) / 2)]
    pts = [t.GetStart(), t.GetEnd()]
    if t.GetClass() == "PCB_ARC":
        pts = [t.GetStart(), t.GetMid(), t.GetEnd()]
    w = mm(t.GetWidth())
    return [Shape(t, t.GetNetname(), (t.GetLayer(),), "seg", ax=mm(a.x), ay=mm(a.y), bx=mm(b.x), by=mm(b.y), w=w)
            for a, b in zip(pts, pts[1:])]


def is_tp(p):
    return p.GetParentFootprint().GetReference().startswith("TP")


# ---------------------------------------------------------------- the board model

EDGES = {}
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

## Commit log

2026-09-26 Record V0 parts: nRF9151 Connect Kit, antennas, Qwiic buzzer, LiPo
2026-09-26 Log board bring-up: modem shell, charger settings, first GNSS test
2026-09-26 First GPS fix, geofence and cue logic with host tests, vendored board files
2026-09-26 V0 firmware: GNSS to geofence to buzzer cue, board overlay, build script
    [buzzer.c, main.c]
2026-09-26 Bottom bay with swappable modules (ballast, GoPro camera, future battery); pulse in top unit
2026-09-26 Product lineup: base collar with ballast; Battery Extension via powered strap; camera add-on
2026-09-26 Wired strap on every collar; modules plug in, battery extension no longer needs its own strap
2026-09-26 Fix stale reliability line after wired-strap change
2026-09-26 Staged shopping list; Blender design tooling plan
2026-09-26 Materials and strap approach for the open, printable collar
2026-09-26 Harness on a bought strap (M8 cordset), 5 V power bus, Battery + Camera module
2026-09-26 DIY (bought strap, unwired) and sold (wired) collar versions
2026-09-26 Verified prototype cart with links
2026-09-26 DIY power path without a software step; battery safety layers
2026-09-26 Mechanical: Blender pipeline and V1-alpha collar draft
    Headless Blender build (mechanical/build.sh) with printability, size and
    clearance checks; bought-part dimensions sourced in lib/dims.py; fit test
    and seal test prints; top unit, clamp bars, bay cradle and ballast module;
    full assembly .blend; share packaging; PLA quick-look slicing for the
    Ender-3 V3 SE via OrcaSlicer. Generated renders and G-code are ignored.
    [bay_ballast_module.stl, bay_cradle.stl, collar_v1_alpha.blend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]
2026-09-26 Collar rule: only cue a crossing; herd_id and moves in the protocol
    An audio cue only teaches when the animal can escape it. The fence is now
    unarmed at boot and after each new boundary until the first inside fix, so a
    boundary drawn over an animal never cues it. This lets openpasture move a herd
    by sweeping boundaries toward a target.
    [main.c]
2026-09-27 Log cart reset to prototype list
2026-09-27 Adafruit cart built after sign-in; correct Qwiic cable price
2026-09-27 Log prototype parts ordered
2026-09-27 Record prototype order receipts
2026-09-27 Document certification reasons and low-budget board design plan
2026-09-27 Set up board design toolchain and document the design phase
2026-09-27 Carrier board spec: charger, sockets, harness port, outline and power budget
2026-09-27 Collar from first principles: mass rule, battery as counterweight, slim crest puck
2026-09-27 Publish repo; move the collar server contract into protocol/
    protocol/contracts.md is the agent kit's docs/contracts.md (commit c306c5c),
    which was never pushed. protocol/README.md now points at it and at the Rust
    app's crates/op-protocol and docs/API.md Device endpoints. Build log entry
    records the pre-publish checks.
2026-09-27 Crest unit + ear pods, symmetric sizing, 8-pin battery harness; carrier spec rev A2
2026-09-27 Carrier rev A2: SKiDL schematic, first placement, LCSC parts
2026-09-27 Firmware 0.2 core: protocol v1 logic with host tests
    Plain C, no Zephyr, so all of it runs on a laptop:
    - shape: the twelve shape rules in openpasture's order, exact int64
    topology on e7 integers, single-precision areas and gaps
    - geofence: outer ring plus up to 16 holes, nearest ring, 384 vertices
    - cue: warn/outside kinds, track mode, episodes
    - command: top-level span scanner, canonical bytes streamed into
    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
2026-09-27 Firmware 0.2 on the board: NVS storage, console, 64 KB partition
    - main.c drives app.c: boot from flash (the latest active boundary at
    once, staged ones on the first GNSS fix), fixes and console lines on
    the main thread so Ed25519 runs on its 8 KB stack
    - store_nvs.c: store.h on Zephyr NVS; console.c: line input on the USB
    serial port for provision, status, boundary and config
    - The compiled-in example boundary is gone; a bench boundary loads as
    version 0 only with CONFIG_OPENCOLLAR_BENCH_BOUNDARY (Kconfig)
    - Board overlay: application 0x08000-0xF0000, storage 64 KB at 0xF0000
    - prj.conf: flash, NVS, main stack 8192, interrupt-driven UART, deferred
    logging so log output never holds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
    [console.c, main.c]
2026-09-27 Protocol README v1, prototype doc and build log for firmware 0.2
    protocol/README.md is rewritten from the field-ready contract's protocol
    v1: limits, boundary and config commands, signing and the collar's
    canonicalization, validation codes and order, geofence and cues, slots
    and their flash records, endpoints, report additions, provisioning over
    USB serial, and the shared test vectors.
2026-09-27 Shrink carrier to 65 x 62 mm: tile plugged boards, parts underneath
2026-09-27 Herd change drops the old herd's staged boundaries
    A signed config naming another herd only changed the herd that new
    boundaries were checked against. The old herd's staged slots stayed in
    RAM and on flash and were applied when due, and they kept `have` above
    the new herd's boundary, so that boundary came back stale.
    slots_set_herd now drops every staged slot whose herd_id isn't the new
    herd (with no ack), and slots_load does the same, which covers a power
    cut after the config is stored and before the deletes. The active
    boundary stays in force until one of the new herd applies. Slots without
    a herd_id stay, as insert accepts them in any herd.
    Spec: herd change bullet under Slots. wrong_he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
2026-09-27 Carrier to 65 x 58.5 mm: harness beside the IMU, SH panel socket, assembled preview
2026-09-27 Test fixture guide from zero: renders on the real board, diagrams, example parts
2026-09-27 Route the carrier: Inky's HeyPCB routing plus a redone charger block
    Inky routed 163 of 166 connections. finish_routing.py re-places the
    bq24074's passives beside the pins they serve, puts fixed fingers on
    U1's 0.5 mm-pitch power pins, reroutes the block with a grid router,
    stitches GND, and pulls the butted Kit sockets' courtyards and silk
    back to the joint. KiCad DRC at every severity: 0 violations, 0
    unconnected.
    [carrier.kicad_pcb, opencollar-carrier.kicad_pcb]
2026-09-28 Carrier rev A3: fuel gauge, flash, reverse protection; fix socket footprints
    Adds the MAX17260 fuel gauge (high-side, 10 mOhm Kelvin sense), W25Q128JV
    flash on the spare GPIOs, and AO3401A reverse-battery protection; charger
    resistors move to JLCPCB basic values. The plug-in sockets switch to
    Pin1Right: JLCPCB's own footprints for the hanxia sockets are the mirror
    of Pin1Left, so A2 couldn't have been assembled.
    finish_routing.py now brings Inky's board up to the schematic and routes
    what changed with Freerouting plus a grid router with rip-up. KiCad DRC at
    every severity: 0 violations, 0 unconnected. New: fit_test.py (1:1 paper
    fit test) and jlc_files.py (BOM and placement from JLCPCB's fo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
    [carrier.kicad_pcb]
2026-09-30 Explain the carrier board part by part, with a labelled render
    docs/CARRIER-EXPLAINED.md: what each component does and how the board
    fits the V1-alpha collar (test box on the crest, ear pods, battery module
    under the throat). Also ignores .DS_Store.
2026-10-01 Add licences: Apache-2.0 code, CERN-OHL-W-2.0 hardware, CC BY 4.0 docs
    Adds LICENSE, LICENSES/, NOTICE (names and logo not licensed) and
    CONTRIBUTING.md (contributions licensed like the files they touch, with
    a relicensing grant to openpasture). Hardware moves from the planned
    CERN-OHL-P to CERN-OHL-W; carrier silkscreen text updated, DRC still clean.
    [carrier.kicad_pcb, opencollar-carrier.kicad_pcb]
2026-10-02 Bench test guide with wiring diagrams
2026-10-26 Print handoff for the V1-alpha print lab
    handoff.sh zips a one-page README, a parts-on-bed sheet and pre-rotated
    STLs. PRINT-LIST notes PA12 and which materials to skip.
2026-10-27 Protocol v2 draft for LoRa-first herds; shared vectors; CI
    protocol/ is now the only normative home: v1 status corrected, contracts.md
    archived, a registry and changelog, and the v2 draft (deterministic CBOR,
    COSE_Sign1 commands, sealed node records, LoRa TDMA binding, anchor
    binding, identity and claim, firmware updates, server obligations, CDDL).
    Vectors live in protocol/vectors with byte-identical copies in the firmware
    host tests, including cue.json and the herd-change case. Fix log lines
    carry GNSS UTC for the bench bridge. SECURITY.md and a CI workflow.
2026-10-27 Protocol v2 draft 2: fixes from the Astra review
    Non-colliding fast slots and honest capacity; device records split to fit
    a frame; per-herd beacon tags; counters that survive power cuts; handover
    bound to its proposal; owner-key release; nRF52840 boot trust and key
    rotation; collar-side install decisions; permanent no-go zones (type 12)
    and activation leases (type 13) held on the collar; bounded reassembly;
    strict CBOR/COSE; a strict Python reference and fuzzing in CI.
2026-11-02 Node V1 print files, P2S print settings and resized cap/pods (#3)
    * Add Node V1 mechanical source and P2S print files
    Commit the Mac-only Node V1 STLs, CAD, Orca profiles, slice scripts, and
    sliced Bambu P2S PLA .gcode.3mf plates so reprints are a GitHub path lookup.
    Sliced F1–F5 projects live under mechanical/print/sliced/p2s_pla/ (not
    print/gcode/, which remains gitignored). P2S machine presets get
    before_layer_change_gcode G92 E0 for Orca 2.4.2. Docs: PRINT-HISTORY,
    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
2026-11-02 Restore dual-cell 18650 pods, fix buzzer address note, log print #3 (#4)
    * Log cap v3 print #3 and note CLI 3mf fix for Bambu Connect
    Mark print #2 as looking great; add print #3 (76×160 gabled cap from
    951e057). Clarify F2/F4 slices are stale, and document fix_bbl_3mf.py
    before Import Gcode 3MF.
    * Restore dual-cell 18650 pods as plan of record
    Cody confirmed 2× Adafruit 1781 (purchase pending) with the original
    identical pods; move the unapproved 353 battery/cue redesign under
    exports/alt_pods_unapproved/. Keep buzzer setAddress()/JP1-volume
    correction and print-history/stale-slice notes; leave the cap alone.
    Co-aut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
2026-11-03 Fix cap insert pockets and lid screws to M3x40 (#5)
    Deepen lid and clamp-bar heat-set insert pockets to ~5 mm so M3x4
    inserts can seat, deepen the base counterbore for ISO 7380 M3x40
    button heads with bonded washers, and document insert counts plus a
    rescue drill for the already-printed cap v3.
2026-11-03 [firmware] MCUboot bootloader + flashable merged.hex (draft) (#7)
    * firmware: build MCUboot + signed app + merged.hex (sysbuild)
    - sysbuild.conf: MCUboot, ECDSA P-256, signed with MCUboot's public DEV key
    (replace before any field build); Kconfig.sysbuild keeps Partition Manager off.
    - boards/partitions_mcuboot.dtsi: NCS 3.4.1 nrf91 bootloader layout, shared by
    app and MCUboot (sysbuild/mcuboot.overlay): MCUboot 64K @0x0, slot0 448K
    @0x10000 (TF-M 32K + app 416K), slot1 448K @0x80000, storage 64K @0xF0000
    (unchanged). All edges 32 KB SPU-aligned.
    - sysbuild/CMakeLists.txt: build/merged.hex = MCUboot + zephyr.signed.hex.
    - check_image.py: image cap 440 KB -> 416 KB (slot0_ns).
    - boar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
2026-11-03 Restructure hardware for Rook and Starling; document repo layout (#11)
    * Restructure hardware for Rook and Starling; document repo layout
    Move mechanical/ into hardware/common (shared CAD/STLs/fasteners) and
    hardware/rook (Node V1 CAD, STLs, print production). Add hardware/starling
    and docs/{rook,starling,assembly} skeletons. Leave firmware/ and protocol/
    untouched; document the op-firmware target layout in docs/REPO-STRUCTURE.md
    against firmware/ARCHITECTURE.md (PR #8).
    * Fix mechanical path in pilot-firmware-spec after hardware split
    ---------
    Co-a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
2026-11-03 [mechanical] Slim cap + printed strap saddle (CAP_STYLE=saddle) (#14)
    Add a selectable slim flat-floor cap (76x160x19) and separate strap saddle
    (76x80x5.9) without overwriting gable v3 STLs under node_v1_cap/. Clamp
    interface unchanged; lid M3x20 / clamp M3x16 for the new stack.
2026-11-03 [mechanical] Print-ready slim cap: pins on saddle, M3x14/M3x18 (#15)
    Move locating pins onto the saddle roof (flank-down print, pins up) and
    put blind Ø4.35×2 sockets in a fully flat cap underside. Clamp M3x14
    (round down for blind pocket); lid M3x18 (M3x20 bottoms). Drop the large
    saddle roof gasket recess that bridged off the bed.
2026-11-03 [mechanical] Assembly aids on bases plate + fit coupon (REV AID1) (#16)
    * [mechanical] Assembly aids on bases plate + fit coupon (REV AID1)
    Add parametrised print-time locators/labels on slim cap + pod bases
    (cradle, L-corners, cable grooves, engraving, dimples), export L/R
    pod bases, test_coupon + scale_bar_100 STLs, and switch slim lid to
    M3x16. Document in ASSEMBLY-AIDS.md / PRINT-HISTORY.
    * [mechanical] Fix AID1 watertight meshes + cradle/buzzer/print log
    Move labels off the bed face (4.5×0.7 on floor/wall), R9.4 cell seat,
    trim buzzer +X/+Y locators, remesh-join coupon pins, add triangulated
    watertight + post-expo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
2026-11-03 [mechanical] AID1: split pod −Y bottom wall labels into two rows (#18)
    * [mechanical] AID1 split pod -Y bottom labels into two rows
    PORT/BUZZER at z≈9 x±22 and M3 LID/INS at z≈3.5 x±18 so four ~25 mm
    labels fit inside x±40 with ≥2 mm horizontal and ≥1.5 mm bed clearance.
    * [mechanical] AID1 pack wall label rows to ≥1.5 mm gaps
    Shrink cells to 4/3/3/3/3 at z 21.5/16.5/12/7.5/3 so five rows fit the
    24.5 mm -Y wall with ≥1.5 mm gaps and M3 bottom ≥1.5 mm above the bed.
    C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
2026-11-03 [docs] Log print #5 aids plate v7 in PRINT-HISTORY (#19)
    Record the slim-cap + pods + coupon + scale plate start (main 7a3660f / PR #18).
2026-11-03 Welfare safeguards: pulse cutoff + auto shut-off (audio V0) (#2)
    * Add welfare safeguards: pulse cutoff and auto shut-off
    Bound outside cues per crossing (default 2), suspend until clear inside,
    auto-shut off after repeated escape/return cycles (default 3/hour), and
    log welfare events. Thresholds are conservative defaults for
    animal-welfare review before pulse hardware.
    * Welfare defaults: 3 cues per crossing, 3 escapes per 24 h (sourced)
    Replace placeholder thresholds with published anchors: Nofence caps an
    escape at three stimuli then switches the fence off (user guide; Norway
    submission); Halter uses daily maximums (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
2026-11-03 Keep auto shut-off until caretaker re-arm (#22)
    A new boundary (cue_rearm) no longer clears welfare auto shut-off or
    resets escape-cycle counters. Only cue_clear_shutoff / serial rearm
    does, per Cody's Nov 3 decision. Update host tests, cue vectors, and
    welfare docs to match.
2026-11-04 docs: claim/handover decisions from record K
    Draft claim and transfer rules in identity.md and server.md: Hand+ may
    claim; same-farm move is notice+24h undo; cross-farm transfer code or
    card; erase claim code at claim (keep claim_check); server reclaim is
    card-only with residual-risk note; lockouts/audit/notices. Collar magnet
    reset unchanged. messages.md left as-is (noted in PR).

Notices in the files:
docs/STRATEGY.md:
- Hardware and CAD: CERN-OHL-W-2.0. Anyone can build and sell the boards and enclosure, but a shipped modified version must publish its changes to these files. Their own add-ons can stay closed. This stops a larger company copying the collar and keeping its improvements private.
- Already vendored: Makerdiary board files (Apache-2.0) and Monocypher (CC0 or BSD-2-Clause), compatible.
